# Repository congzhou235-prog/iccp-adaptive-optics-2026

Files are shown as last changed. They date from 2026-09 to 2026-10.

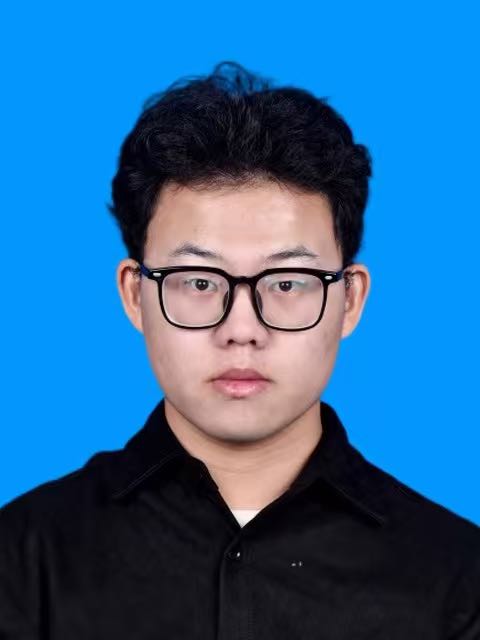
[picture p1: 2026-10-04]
lecturer&TAs pictures/jinxinliu.jpg

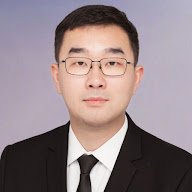
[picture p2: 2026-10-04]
lecturer&TAs pictures/shuqimu.jpg

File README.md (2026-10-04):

# ICCP Adaptive Optics Mini-Course 2026

Build a Shack-Hartmann sensor and learn to measure wavefront aberrations.

**[Open the course website](https://congzhou235-prog.github.io/iccp-adaptive-optics-2026/)**

## Course materials

- [Course notes](Hartmann%20Sensor%20Course%20Notes.pdf)
- [Lecture 1 introduction slides](Lecture1_introduction.pdf)
- [Hardware and parts list](hardware/README.md)
- [Assembly guide](Assembly%20Guide%20for%20the%20Hartmann%20Sensor.pdf)
- [Offline image analysis tutorial](sh_tutorial_prog/README.md)
- [Tutorial notebook](sh_tutorial_prog/main.ipynb)
- [Tutorial code and data on GitHub](https://github.com/congzhou235-prog/iccp-adaptive-optics-2026)

Lecturer: [He Sun](https://hesunpu.github.io/index.html) · Teaching assistant: [Shuqi Mu](https://scholar.google.com/citations?user=fEJv1TwAAAAJ&hl=en)

Visit the [PKU Computational Scientific Imaging Lab website](https://ai4scientificimaging.org/) to learn more about our group.

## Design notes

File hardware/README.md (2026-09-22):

# Shack-Hartmann sensor hardware

[Hardware section](../index.html#hardware) · [Parts list (CSV)](BOM.csv) · [Illustrated assembly guide](../Assembly%20Guide%20for%20the%20Hartmann%20Sensor.pdf)

The sensor uses a DAHENG VEN-161-61U3M bare-board camera, an LBTEK MLAS10-F15-P300-AB mounted microlens array, an SM1-12.5A lens tube, and a printed front and back housing.

## Supplier pages

- [Camera: VEN-161-61U3M](https://en.daheng-imaging.com/show-93-2117-1.html). Select the bare-board version without a lens mount for this housing.
- [Microlens array: MLAS10-F15-P300-AB](https://en.lbtek.com/product/378). Pitch: 300 µm. Focal length: 14.6 mm. Mount diameter: 25.4 mm.
- [Lens tube: SM1-12.5A](https://en.lbtek.com/product/221). Includes one SM1R retaining ring. The assembly needs two rings in total, so add one extra.

- [Retaining ring: SM1R](https://en.lbtek.com/product/135#SM1R). SM1 external thread, 2.0 mm thickness, Ø23.0 mm clear aperture, for Ø25.4 mm optics. Black anodized 6061-T6 aluminum alloy. Two rings are needed in total, including the one supplied with the lens tube.

Quantities in the CSV are for one sensor. Also prepare clean gloves, a computer with the camera driver and Galaxy Viewer, and a collimated beam for adjustment.

## Printed parts

The front housing holds the camera board and has an SM1 opening. The back housing secures the board and leaves the camera connector accessible. Four M2 screws and four M2×2 brass insert nuts join the two parts.

[Download both STEP models (ZIP)](../downloads/camera-housing-step.zip). Extract the archive to get a `camera-housing` folder containing both files.

Individual files:

- [hartmann1.STEP](../hartmann1.STEP)
- [hartmann2 - 0923new.step](../hartmann2%20-%200923new.step)

Dimensions for M2×2 from the supplier’s table (all in mm):

| Model | Length | Pilot hole diameter | Workpiece outer diameter |
| --- | --- | --- | --- |
| M2×2 | 3.5 | 3.2 | 6.2 |

The 6.2 mm value describes the workpiece outer diameter, not the nut outer diameter.

During printing, pause when the housing’s recessed holes are accessible. Use M2×2 brass insert nuts to fit the reserved holes. Press the four nuts into the recesses, then resume printing. Use the embedded nuts to secure the housing with the M2 screws.

Choose a strong printing material with good heat resistance. The specific material, print settings, and STL files are still to be added.

## Assembly

Follow the PDF for the illustrated steps: install the camera and housings, mount the array between two rings, attach the tube, connect the camera, and adjust focus and alignment. Tighten the housing screws and retaining rings gently.

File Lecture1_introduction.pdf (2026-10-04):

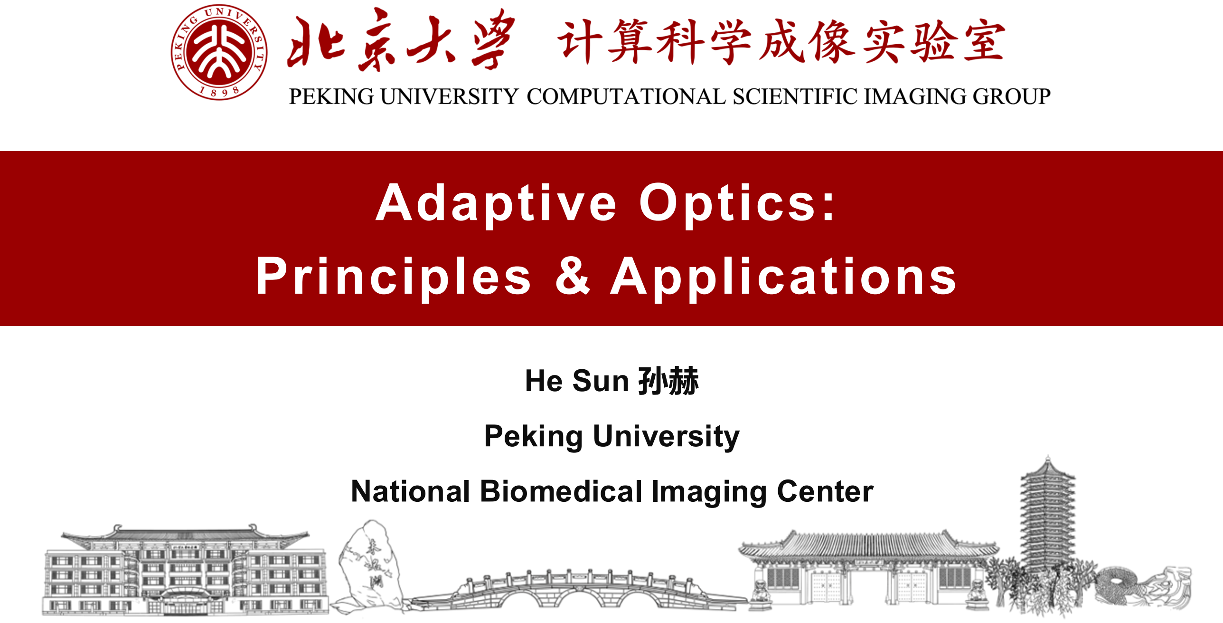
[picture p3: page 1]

## He Sun 孙赫

## Peking University

## National Biomedical Imaging Center

# Adaptive Optics: Principles & Applications

## What is Adaptive Optics?

## Adaptive optics (AO) is an ensemble of electro-optical and computational

methods that aim to recover the optimal performance of an optical system.

It is by nature interdisciplinary, related to optics, signal processing, control, etc.

## Science & Art of manipulating light physically & algorithmically

## — Nature Reviews Methods Primers 2021

## Adaptive Optics v.s. Computational Imaging

## Computational AO was proposed more than 20 years ago for correcting aberrations by … correcting the effects of the aberrations using deconvolution…

## Physical correction is preferred over deconvolution because the additional measurement of the corrected image yields additional photons, substantially increasing the signal to noise ratio …

This fact applies to AO in general and should not be understated.

## — Nature Reviews Methods Primers 2021

## History of Adaptive Optics – Newton’s Concern

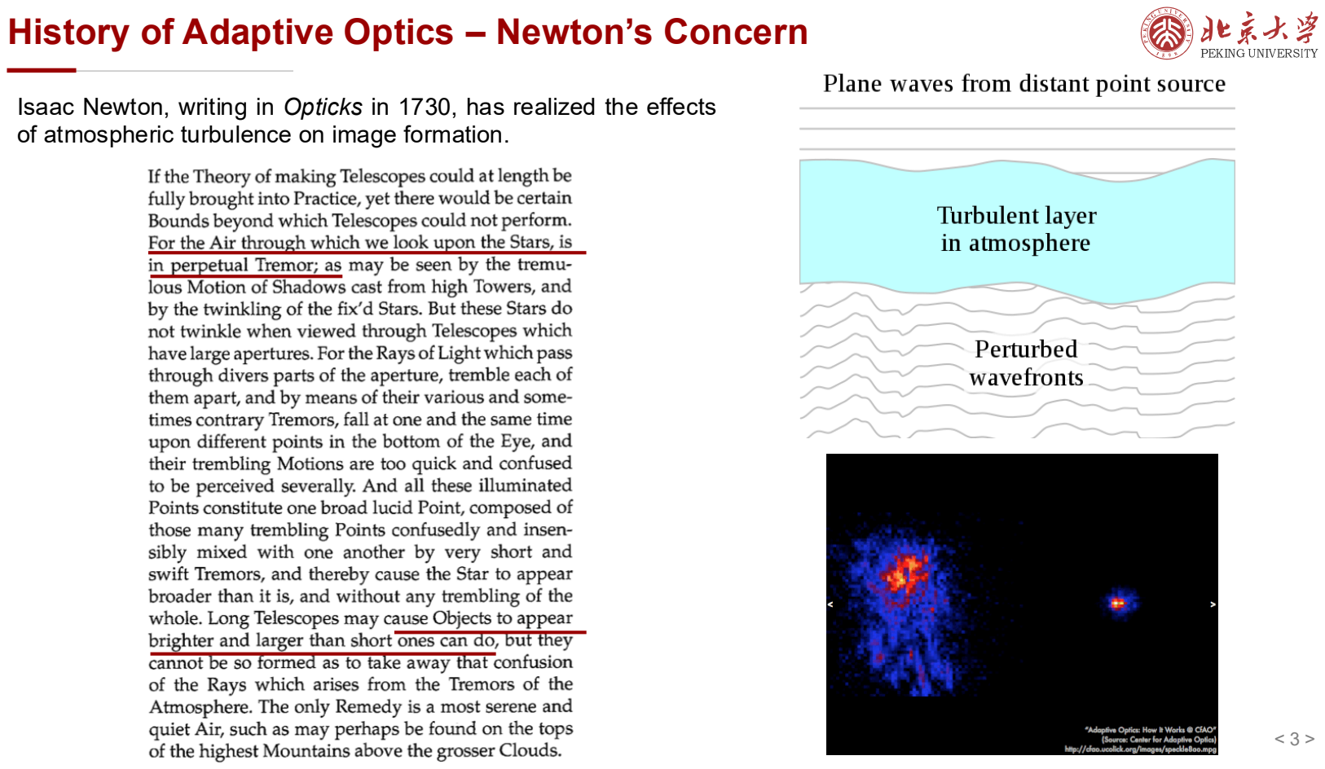
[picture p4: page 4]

Isaac Newton, writing in Opticks in 1730, has realized the effects of atmospheric turbulence on image formation.

## Wavefront Aberrations

Wavefront is defined by the spatial locations that share the same phase.

Optical aberrations can be understood as deformations of the light’s wavefront from its perfect form -planar for a collimated beam or spherical for a focusing beam - that produces the sharpest image

## Astronomical Seeing & Diffraction Limit

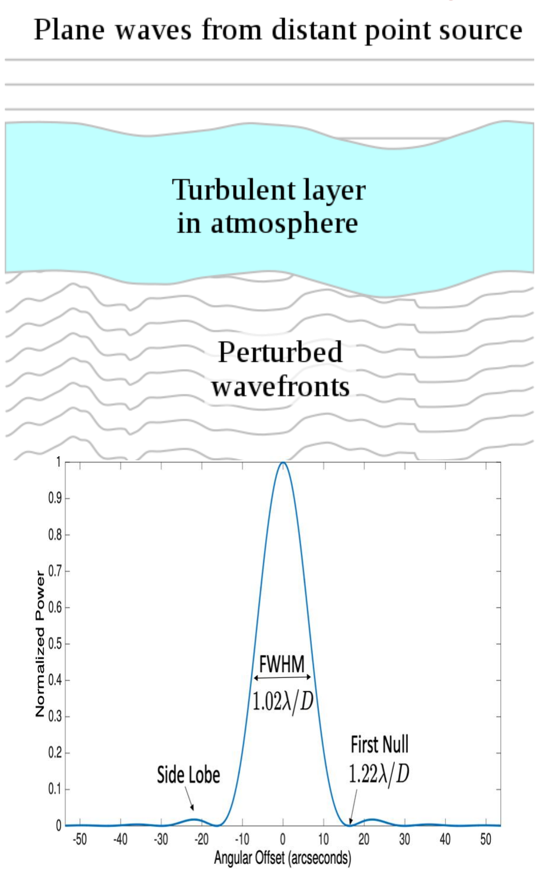
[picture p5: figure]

Seeing is the degradation of the image of an astronomical object due to turbulence in the atmosphere of Earth that may become visible as blurring, twinkling or
variable distortion.

Diffraction-limited image (Airy-pattern image)
R = 1.22 f λ/D

The model assumes that the wavefront perturbations are brought about by variations in the refractive index of the atmosphere.

Seeing is a major limitation to the angular resolution in astronomical observations with telescopes that would otherwise be limited through diffraction by the size of the telescope aperture.

## Statistical measure of atmospheric turbulence – r0 & t0

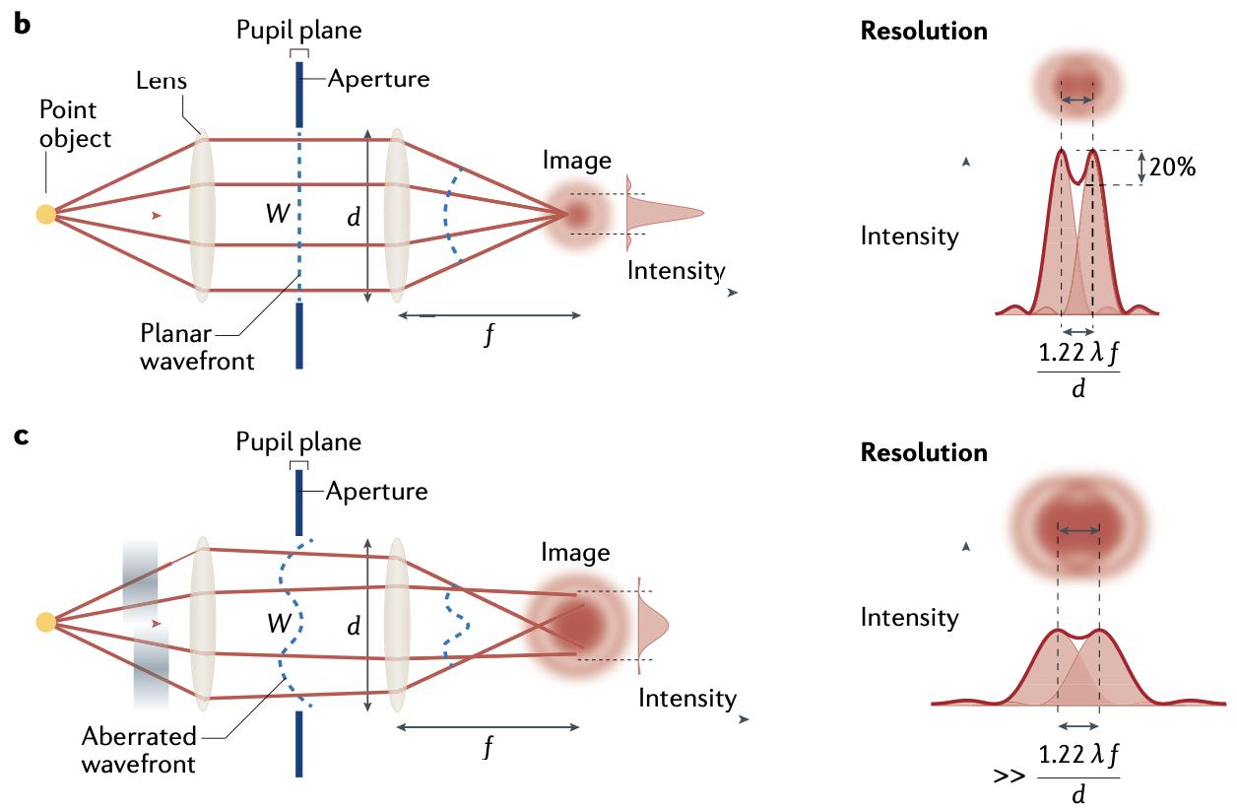
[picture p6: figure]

Coherent length or Fried parameter (r0

)
→ a statistical measure of the turbulence’s spatial frequency
→ around 10cm at visible wavelength at good site
→ telescope diameter < r0
, diffraction limit
defined by the telescope size; → telescope diameter > r0
, diffraction limit
defined by r0

Coherent time (t0

)
→ a statistical measure of the turbulence’s jiggling rate
→ on the order of 1ms

## Newton’s Proposal

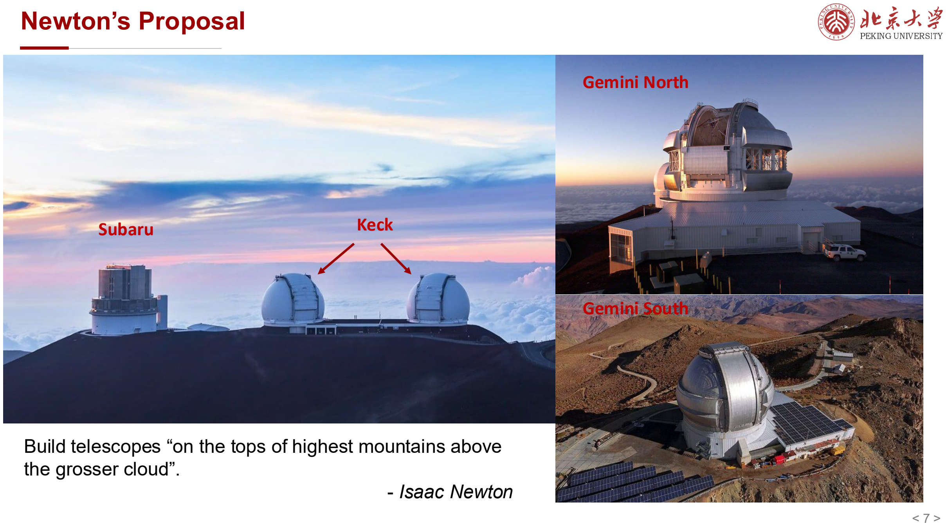
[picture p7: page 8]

Build telescopes “on the tops of highest mountains above the grosser cloud”.
- Isaac Newton
Subaru | Keck

Gemini North

Gemini South

## Newton’s Proposal

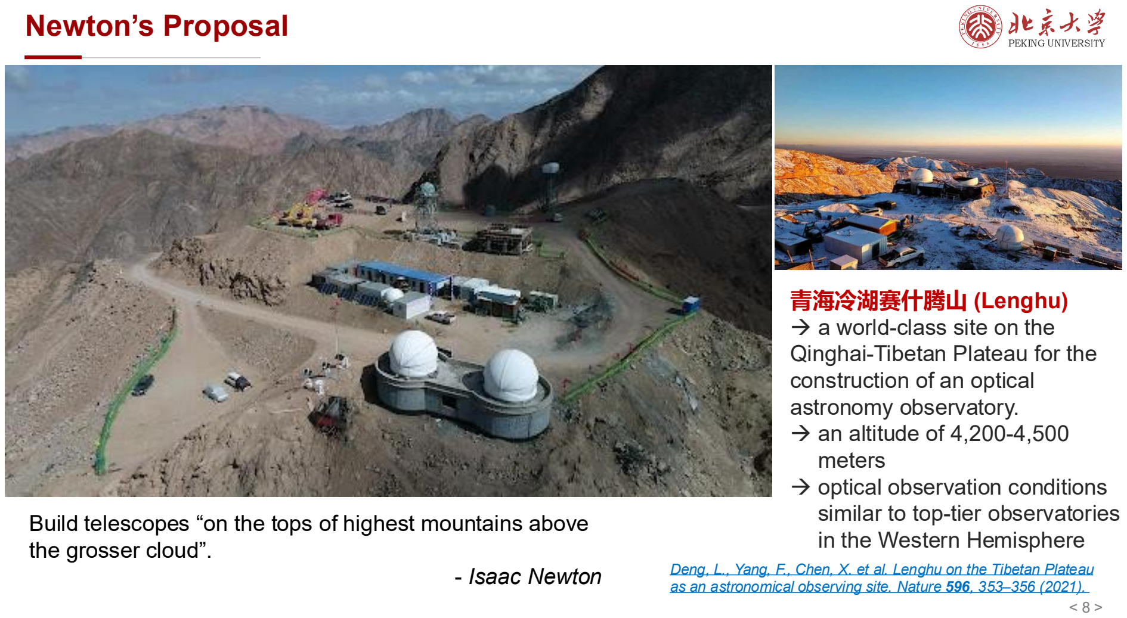
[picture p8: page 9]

Build telescopes “on the tops of highest mountains above the grosser cloud”.
- Isaac Newton

青海冷湖赛什腾山 (Lenghu)
→ a world-class site on the Qinghai-Tibetan Plateau for the construction of an optical astronomy observatory.
→ an altitude of 4,200-4,500 meters
→ optical observation conditions similar to top-tier observatories in the Western Hemisphere

Deng, L., Yang, F., Chen, X. et al. Lenghu on the Tibetan Plateau as an astronomical observing site. Nature 596, 353–356 (2021).

## 1950s - Babcock’s & Linnik’s Proposal

- 1953 AO seminal paper: "The Possibility of Compensating Astronomical Seeing”, PASP
- All basic building component is here
- Beam Splitter
- Wavefront Sensor & Corrector
- Close-loop Arrangement

Horace Babcock (U.S.A.)

V. P. Linnik (U.S.S.R) | Babcock’s Design
- 1957 Independent proposal for adaptive optics systems and their limitations, Opt. Spectrosc.
- First describe the artificial guide star

## 1960s – 1980s - AO Development During Cold War Years

- 1970s: DARPA (Defense Advanced Research Projects Agency) looks for a mean of identifying/imaging USSR low earth orbit satellites.
- Imaging fast moving target (>10kHz) in any seeing conditions, visible wavelength.
- Many technologies to develop:
- fast wave-front sensing (shearing interferometer)
- Reconstructor (analog, array of resistor; local)
- DM: Feinlieb et al ➜ MPM* 21 actuators
- More AO theory: WFSs for white light, extended sources.
- 1973-1974: the Real-Time Atmospheric Compensator (RTAC).
- 1973: First close loop lab test ever. Very successful.
- 1974: First RTAC field tests. Successful.
- 1980s: Strategic Defense Initiative (SDI) – Star War Program
- Ballistic Missile Defense
- Anti-Satellite
- 1990s: Many technologies declassified due to the end of cold war

AO off

AO on

AO on +
post-processing

1990s

## - Astronomical AO

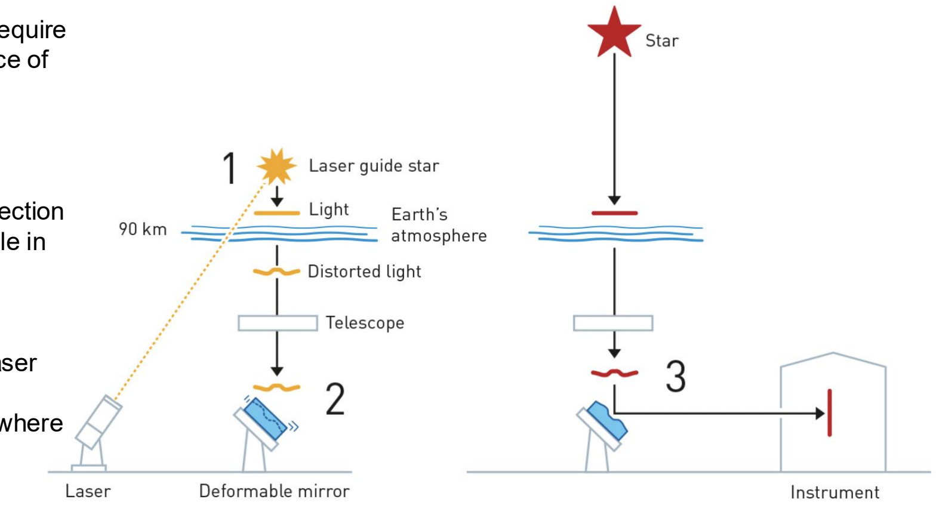
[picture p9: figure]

< 11

>

- Astronomical AO systems require a wavefront reference source of light called a guide star. • Natural guide star (NGS) • Ideal point source for

wavefront sensing/correction
- Bright stars not available in all parts of sky
- Laser guide star (LGS) • Created by shining a laser

into atmosphere
•

Can be positioned anywhere in the sky

## Laser Guide Star：Rayleigh Beacon v.s. Sodium Beacon

Rayleigh beacons
→ rely on the scattering of light by the molecules in the lower atmosphere around 20km altitude.
→ simple and inexpensive
→ cone effect: only measures the portion of atmosphere below the guide star

Sodium beacons
→ created by using a laser tuned to 589.2 nanometers to energize atoms in the sodium layer of the mesosphere at around 90 km altitude. The sodium atoms then re-emit the laser light, producing a glowing artificial star.

## Keck Telescope AO

- 1999: First light for AO on the Keck II telescope.
- First AO system for a new generation of 8–10 m telescopes,
- natural guide star system
- consisted of a separate tip–tilt corrector, a 349 actuator deformable mirror and a SH wavefront sensor
- Strehl ratios of up to 0.37 in H band (1.6 μm)
- dramatic improvements in image quality afforded by AO on large ground-based telescopes. The original Keck AO systems
- 2001: sodium LGS installed
- significantly improved sky coverage
- 2008: wavefront sensor and control upgraded
- Improved the sampling, frame rate and lantency
- Improved Strehl ratio and faint star limits for natural guide star and LGS modes86

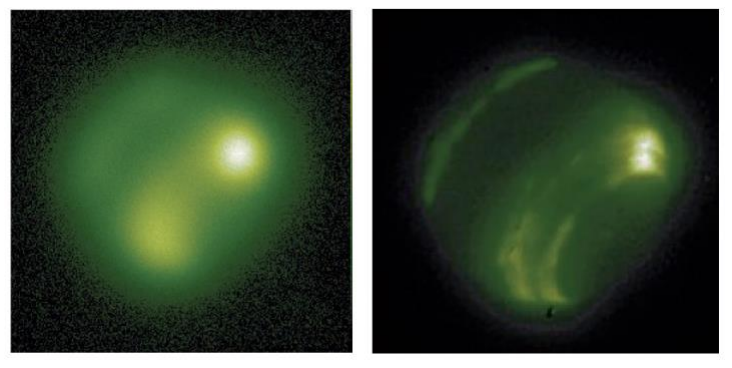
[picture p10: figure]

Neptune before and after AO correction

W. M. Keck Observatories

## AO for Black Hole Discovery

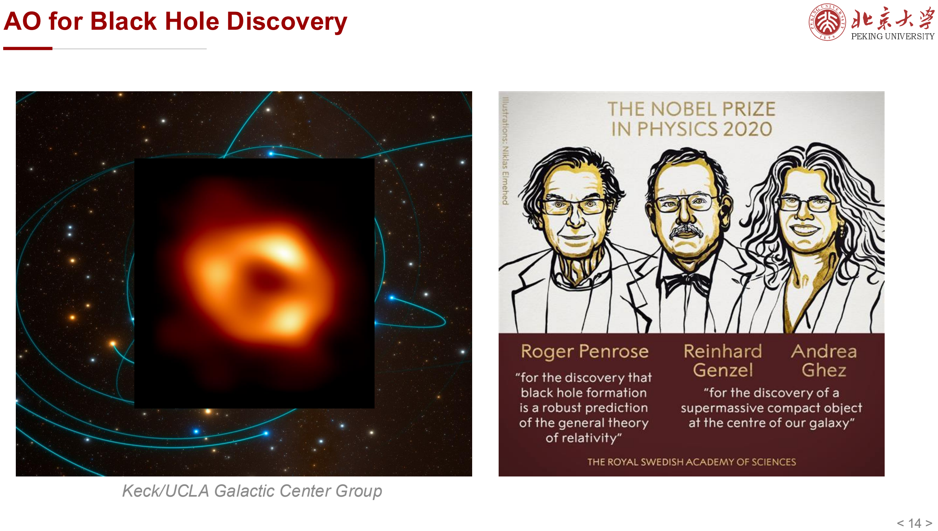
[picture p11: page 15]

Keck/UCLA Galactic Center Group

## Extreme AO – High Contrast Imaging of Exoplanets

The science target acts as the NGS.

HR8799 bcde

## AO cannot replace space facilities

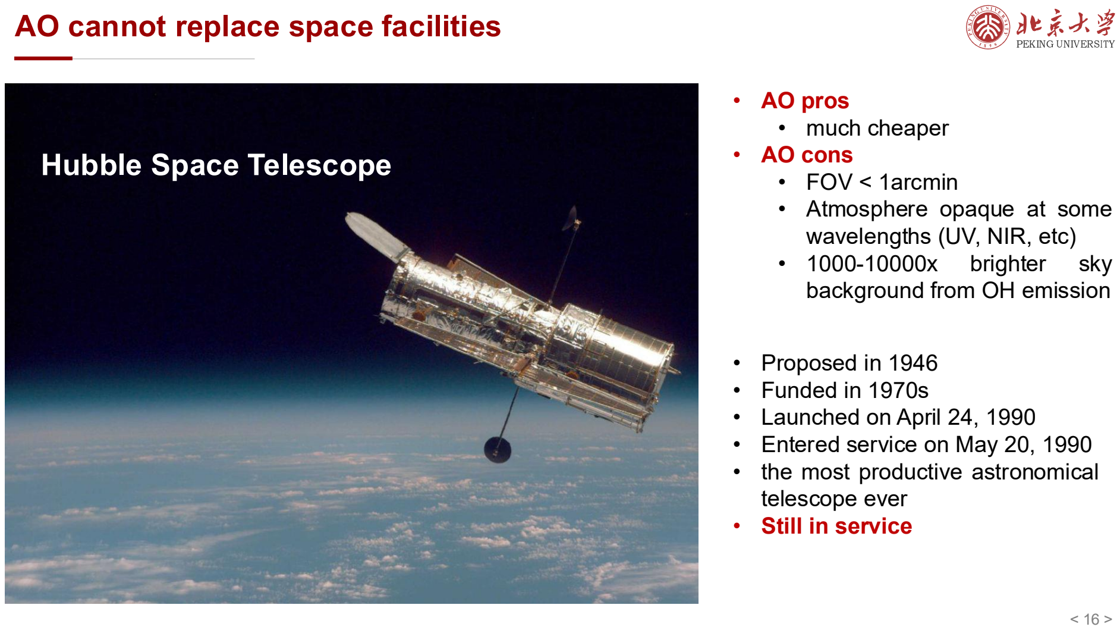
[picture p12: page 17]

- Proposed in 1946
- Funded in 1970s
- Launched on April 24, 1990
- Entered service on May 20, 1990
- the most productive astronomical telescope ever
- Still in service

## Hubble Space Telescope

- AO pros
- much cheaper
- AO cons
- FOV < 1arcmin
- Atmosphere opaque at some wavelengths (UV, NIR, etc)
- 1000-10000x | brighter | sky
background from OH emission

## Success of Hubble Space Telescope (HST)

Star birth in Eagle Nebula (Nov 2, 1995)

Hubble deep field image
(Jan 15, 1996)

## Back to 1990s: HST’s Flawed Mirror

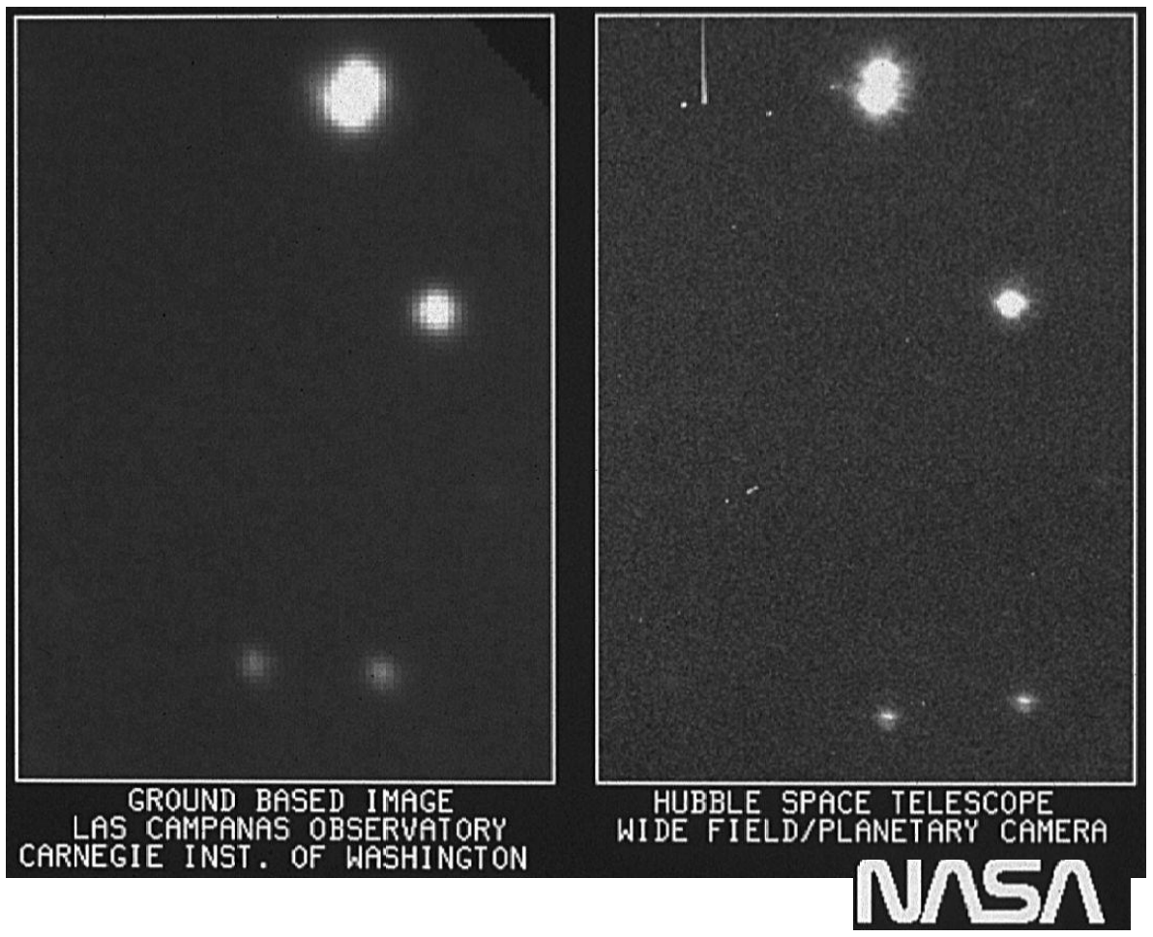
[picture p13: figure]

## Back to 1990s: HST’s Flawed Mirror

## Rescuing Hubble Space Telescope (HST)

Collect aberrated
images from HST

Characterizing
mirror flaws by
phase retrieval | Deploy corrective
| optics instrument

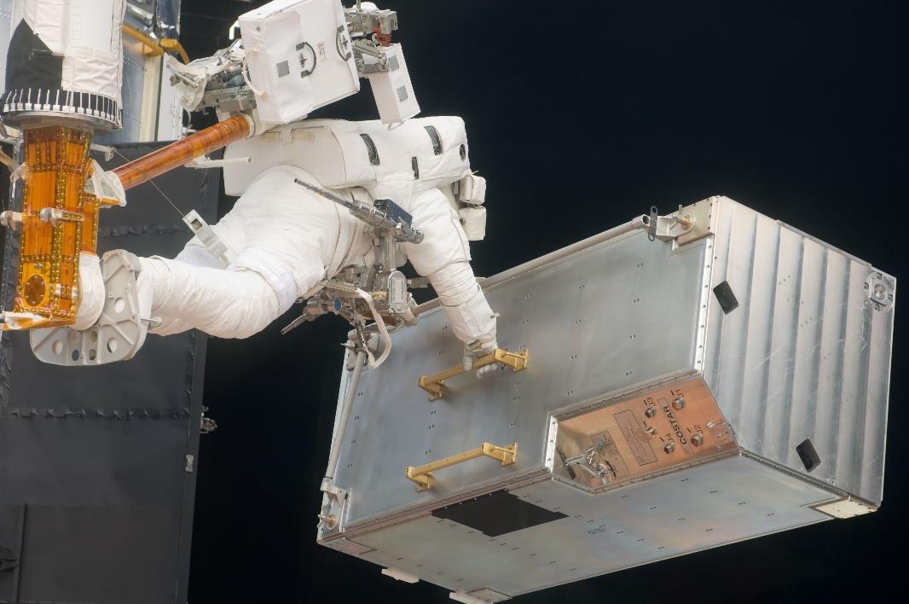
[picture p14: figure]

1993
HST Servicing
mission

Image processing
via deconvolution

## Rescuing Hubble Space Telescope (HST)

22

## Late 1990s - Vision AO

Aberrations in vision AO
- Eye’s imperfect optics
- Diffraction caused by the finite size of the eye’s pupil (1–8 mm diameter)
- Diffraction can be minimized by dilating the pupil with mydriatic drops. However, this benefit comes at the cost of additional aberrations exposed by dilation
- AO increases lateral resolution by a factor of up to five
- AO increases sensitivity as it allows a larger pupil to be used and more reflected light to be captured by the ophthalmoscope.

AO-OCT reveals thousands of individual cone photoreceptor cells spaced 4.5 μm apart that would otherwise not be seen

AO-OCT

## Early 2000s - Microscopic AO

2002 AO was first extended to the field of microscopy.

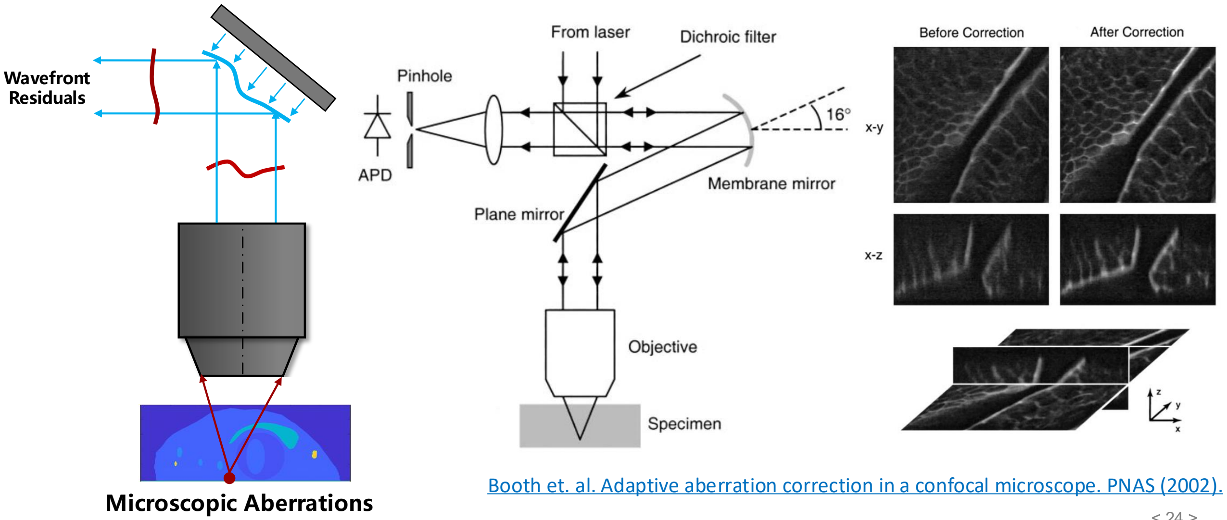
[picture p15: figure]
Wavefront Residuals; Microscopic Aberrations

Booth et. al. Adaptive aberration correction in a confocal microscope. PNAS (2002).

## Microscopic AO corrects illumination & emission light

Wide-Field (Emission) | Point Scanning (Excitation) | Light-Sheet (Emission & Excitation)

## Recent Progress: Multi-photon & Super-resolution

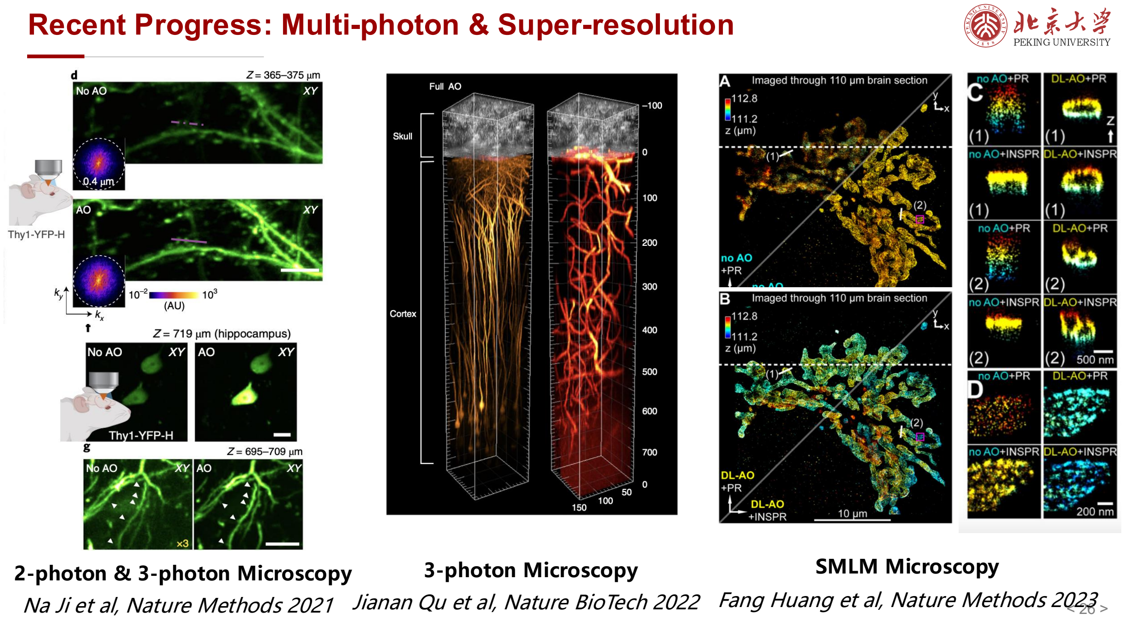
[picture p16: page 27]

2-photon & 3-photon Microscopy Na Ji et al, Nature Methods 2021

SMLM Microscopy
Fang Huang et al, Nature Methods 2023

3-photon Microscopy
Jianan Qu et al, Nature BioTech 2022

## A Representative AO System

Three main components of AO:
- a sensor to measure the aberrations
- a corrector to compensate the aberrations
- a controller that calculates the required signals sent to the corrector based on the sensor measurements.

The corrector and sensor are typically conjugate to the pupil plane of the imaging system, which means that the pupil is imaged on to the corrector and sensor.

## Representing the Wavefront - RMS errors & Zernike Polynomials

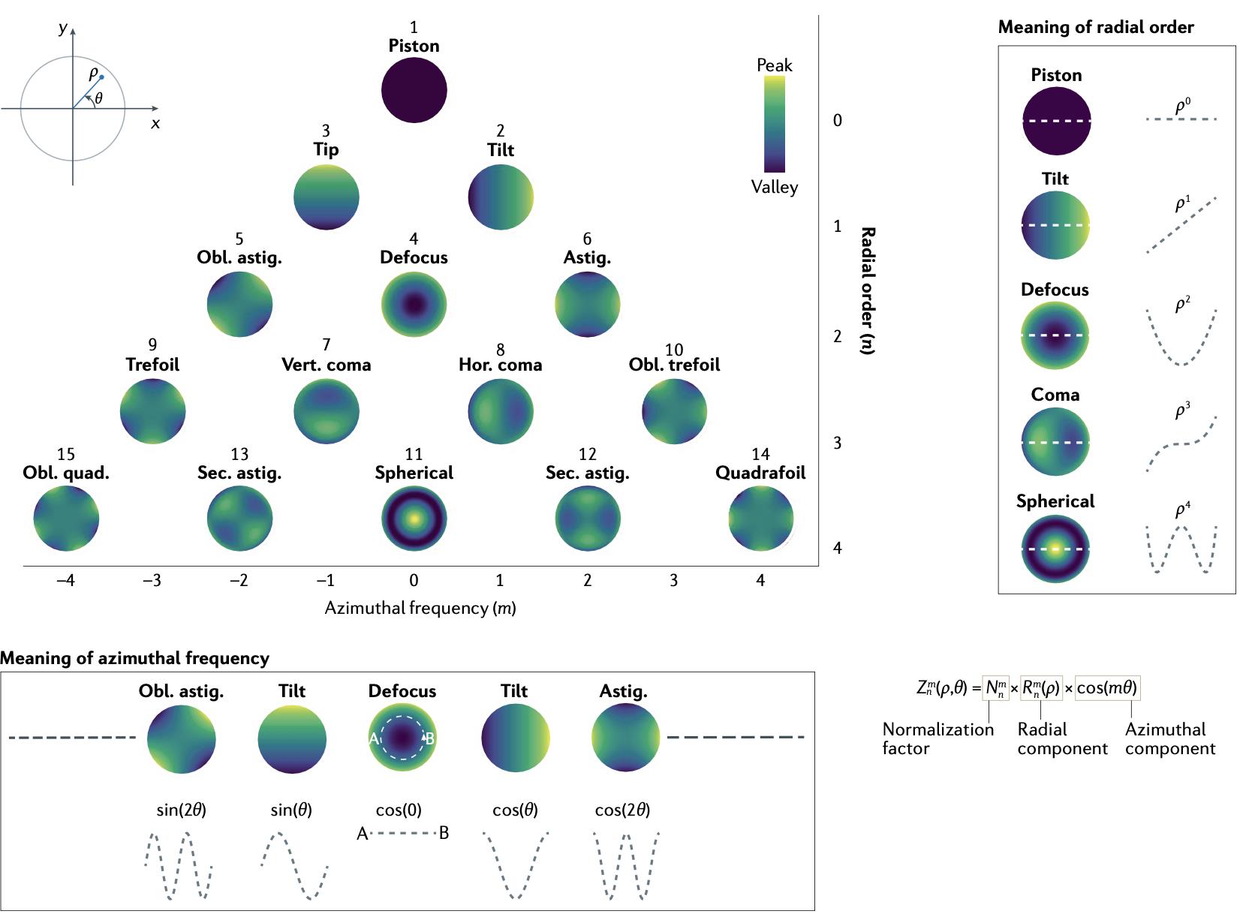
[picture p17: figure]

- Aberration modes are often broadly categorized as being of lower order or higher order.
- The definition of lower order and higher order varies
between fields.
- Higher order is typically defined as modes with a radial order above three for astronomy, above two for vision science and above four for microscopy.

## Wavefront Sensing – Direct Sensing

## Wavefront Sensing – Indirect Sensing

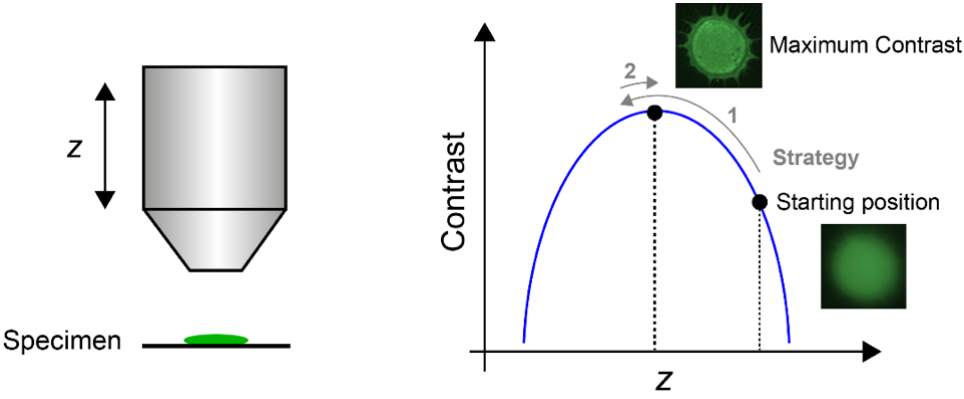
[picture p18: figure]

## Wavefront Sensing – Indirect Sensing

## Wavefront Control – Phase Conjugation

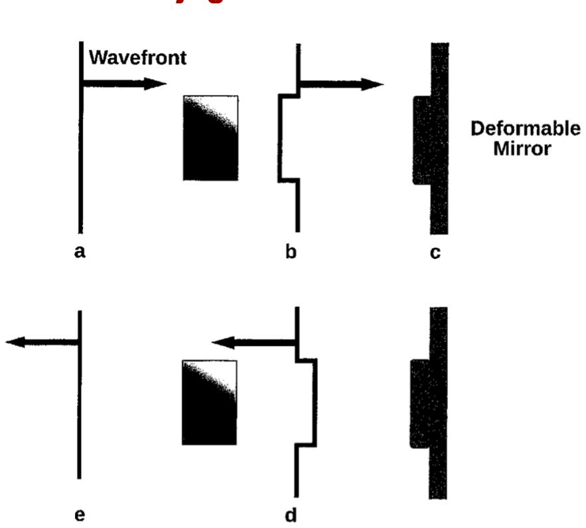
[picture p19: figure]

Apply an opposite shape of wavefront error on the corrector

## Wavefront Control - Correctors

a. Deformable mirrors (DMs) consist of a reflective surface that may be continuous or segmented.
b. Liquid crystal spatial light modulators (LCSLMs) consist of pixels that are able to change their refractive index, n.
c. Deformable phase plates are fluidic devices that are able to change their shape.

## Wavefront Control - Correctors

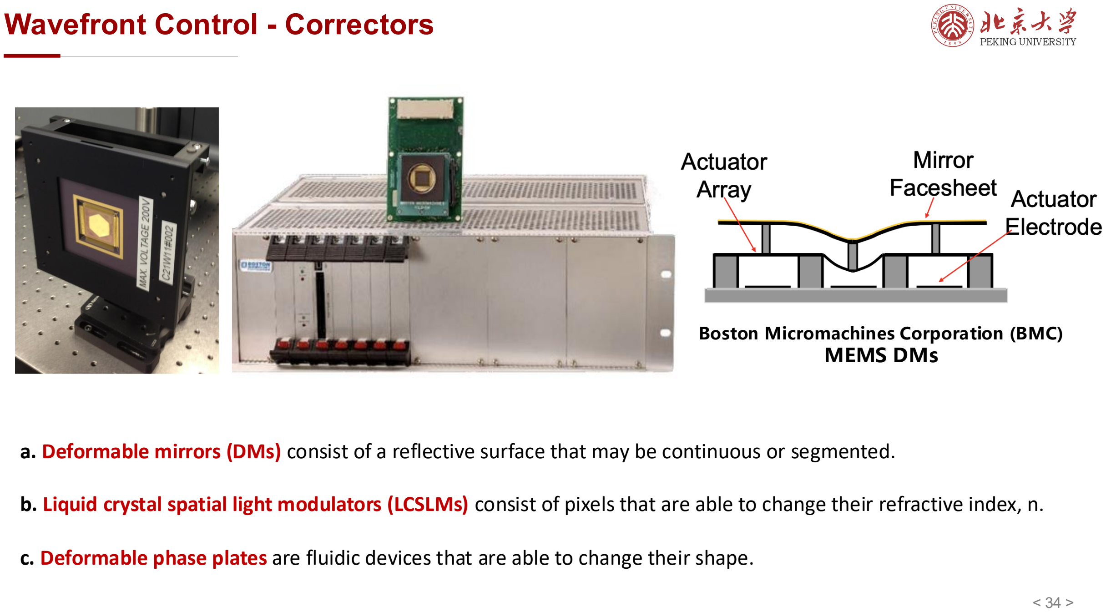
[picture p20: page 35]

a. Deformable mirrors (DMs) consist of a reflective surface that may be continuous or segmented.
b. Liquid crystal spatial light modulators (LCSLMs) consist of pixels that are able to change their refractive index, n.
c. Deformable phase plates are fluidic devices that are able to change their shape.

Boston Micromachines Corporation (BMC) MEMS DMs

## Basic Concept – Strehl Ratio

Strehl Ratio: The ratio of the intensity of the peak of the aberrated point spread function (PSF) to that of the diffraction-limited PSF.

To achieve diffraction-limited resolution, which is equivalent to a Strehl ratio of 0.8 or above, AO must reduce this distortion to less than λ/14.

## Basic Concept – RMS Error

RMS wavefront error is a useful descriptor to capture the severity of the aberrations in a system.
RMS = E | W − E | W | 2

1/2

The Maréchal Approximation： Strehl Ratio ~ exp −σ

2 = exp −(2π RMS/λ)

2
Another empirical rule： phase variance = σ

2 = 1.03 D/r0

5/3

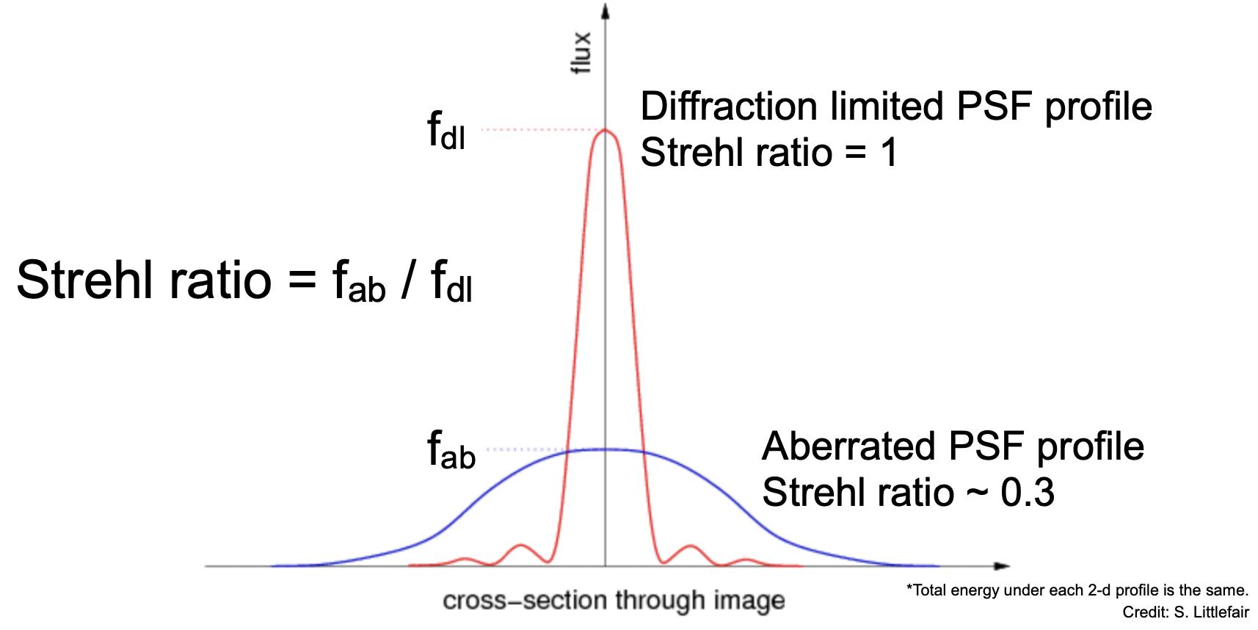
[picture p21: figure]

## Basic Concept – Isoplanatic Patch

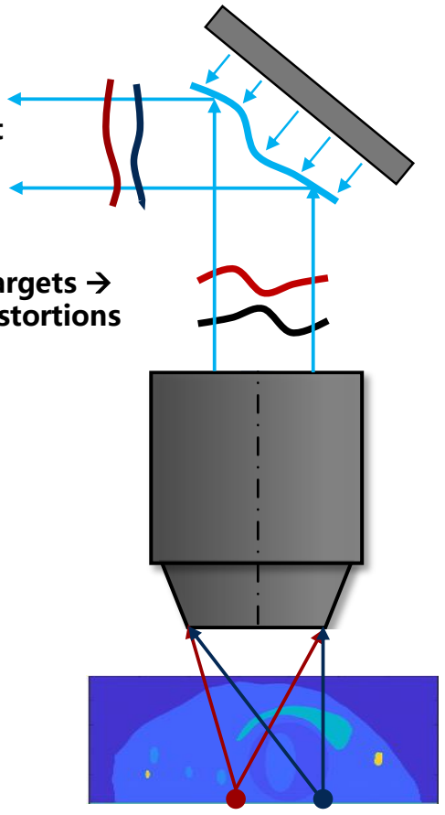
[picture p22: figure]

Isoplanatic patch: The area over which the aberrations can be considered invariant.

- astronomy: 1.5 to 2 arcsec at 0.5μm Isoplanatic path ∝ 1.03 D/r0

6/5

- vision science: 1°, or 300 μm at the retina
- microscopy: hundreds of microns, in mouse brain for example, to a few microns, such as inside tissue with high curvature or complexity, for example, zebrafish larvae or Caenorhabditis elegans.

### Classification of AO systems: Single-Conjugate v.s. Multi-Conjugate

Single Conjugate AO (SCAO), i.e. classical AO, → a single DM conjugated to turbulence in a single atmospheric layer.
→ a moderate FOV at a moderate Strehl ratio.

Ground Layer AO (GLAO)
→ a single DM conjugated to ground level.
→ Large FOV at low Strehl ratio

Multi-conjugate AO (MCAO)
→ multiple WFSs and DMs conjugated to multiple atmospheric layers and requires multiple guide stars. → Large FOV at moderate Strehl ratio

MCAO

Classicial AO

Francois Rigaut et al, MNRAS 2014

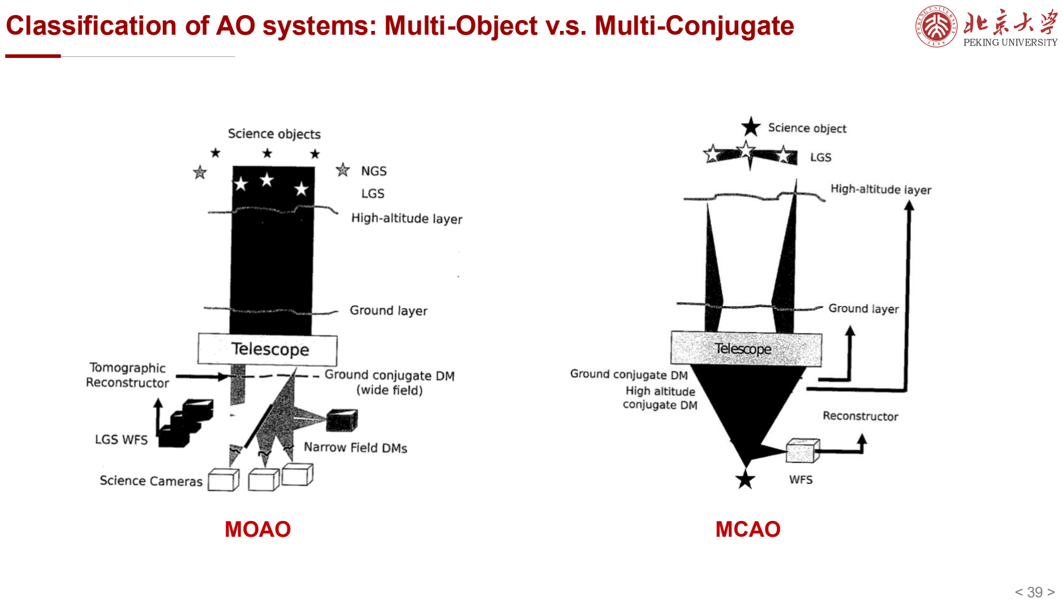
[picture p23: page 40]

### Classification of AO systems: Multi-Object v.s. Multi-Conjugate

MOAO | MCAO

## Classification of AO systems: Sensorless or Sensor-based

Pros of sensorless AO:
- It requires no extra hardware → low cost
- There are no non-common path errors,
- All light is used for imaging → good for low light case
- It can be used in situations where sensing may not be possible owing to the nature of the light returning from the sample → deep tissue imaging

Cons of sensorless AO:
- Speed → photobleaching, live specimen motion, mechanical drift https://aomicroscopy.org/sensorless-ao

Sensor-based AO consisted of a wavefront sensor for aberration measurement.

Sensorless AO requires no sensor, but infers the wavefront aberrations from a sequence of images.

## Classification of AO systems: Point v.s. Extended Source

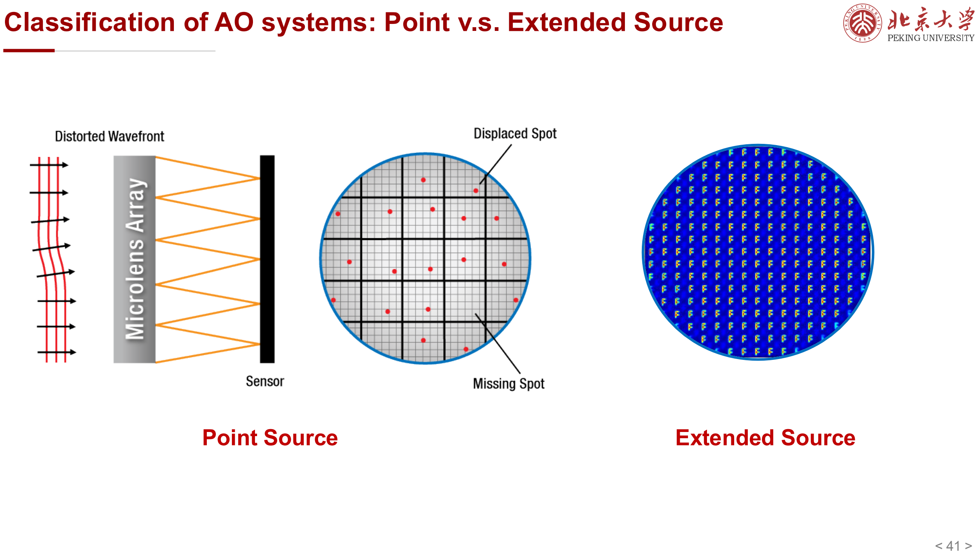
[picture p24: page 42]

Point Source | Extended Source

## Classification of AO systems: Zonal v.s. Model Correction

The wavefront errors can be corrected either zonally or modally.

In the zonal case, the pupil is considered to consist of segments that are individually controlled. Zonal techniques are typically carried out using phase-only liquid crystal spatial light modulators (LC-SLMs) or segmented deformable mirrors. Piston-only or piston, tip and tilt are modulated, depending on the corrector.

In the modal case, the wavefront shape across the entire pupil is changed sequentially. Consequently, this method is more suitable for continuous surface correctors such as continuous surface deformable mirrors. Each mode could be a Zernike polynomial, for example.

## Classification of AO systems: AO v.s. Wavefront Shaping

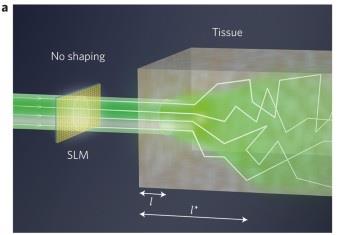
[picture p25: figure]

AO and wavefront shaping are identical, except for the controller’s degrees of freedom.

AO is mainly correct for smooth aberrations.

## Wavefront shaping compensate both scattering and aberrations (mainly scattering) and have guaranteed convergence even for

finding high-dimensional corrections.

## Astronomical AO v.s. Vision AO v.s. Microscopy AO

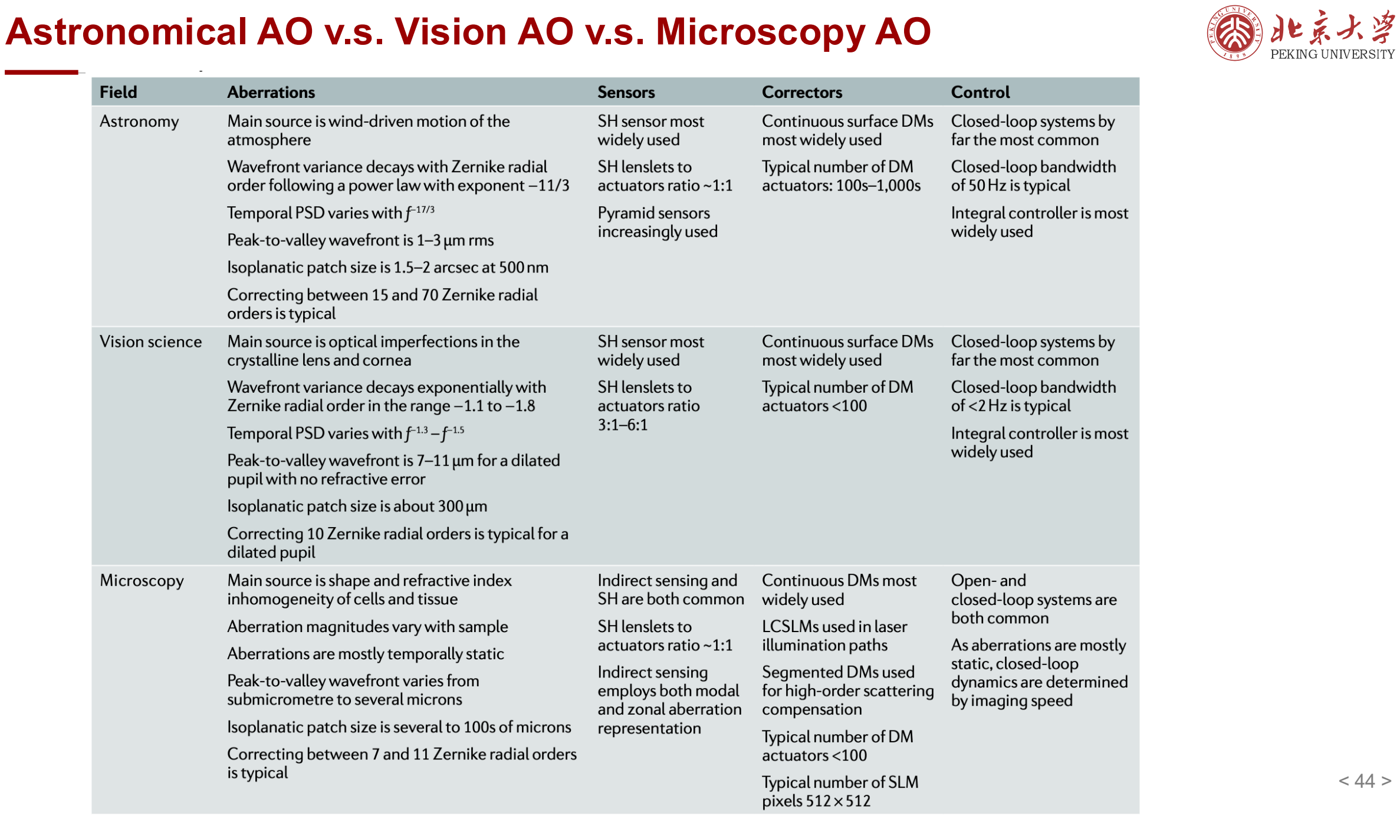
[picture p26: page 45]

## Analysis of AO System

< 45

>

Problem:
Science Target:
Wavelength Range:
Statistics of Aberrations: ⋯

Hardware&Software

:
Sensor:
Corrector:
Algorithm:

Result:
FOV:
Speed:
Resolution:
Contrast:

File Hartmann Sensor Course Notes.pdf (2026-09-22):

## Hartmann Sensor Course Notes

## 1 Light and Wavefronts

Before we build a Hartmann sensor, we need to understand one important idea:

Light is not only a ray. Light is also a wave.

A simple way to imagine a wave is to think about water ripples. If we drop a small stone into water, circular ripples spread outward. Light also has a similar wave-like behavior, although we usually cannot see the wave directly.

### 1.1 What is a wavefront?

A wavefront is a surface connecting points of a light wave that are at the same stage of vibration. In simple words:

Key Idea

A wavefront shows the shape of light as it travels.

The direction of light propagation is usually perpendicular to the wavefront. So if we know the shape of the wavefront, we can understand how the light is moving.


Figure 1: Three examples of wavefronts: planar wavefront, spherical diverging wavefront, and distorted wavefront. The black arrows show the direction of light propagation. The purple curves show the wavefronts.

In a perfect world, light would travel smoothly. But in real optical systems, many things can disturb the wavefront:

- imperfect lenses,
- turbulent air,
- biological tissue,
- misaligned optical components.

After passing through these disturbances, the wavefront is no longer flat or spherical. It becomes a distorted wavefront.

### 1.2 Why do we care about wavefronts?

In imaging systems, the quality of the image is strongly related to the quality of the wavefront. If the wavefront is flat and smooth, the image can be sharp. If the wavefront is distorted, the image may become blurry.
So our goal is:

Measure the wavefront, understand the distortion, and correct it.

This is the basic idea behind adaptive optics.


Figure 2: Ideal and irregular wavefronts in an imaging system. In the ideal case, light rays focus well and form a sharp point. In the irregular case, the distorted wavefront prevents the rays from meeting at one perfect focus, so the image becomes blurred.

This is similar to how the human eye forms an image. In a healthy eye, the wavefront is smooth, so light can focus well on the retina and we see a clear image. But if the cornea or lens is not perfect, the wavefront becomes distorted. Then the light cannot focus into a sharp point, and the image becomes blurry.

### 1.3 A Simple Language for Wavefronts: Zernike Modes

A distorted wavefront can have many different shapes. Some distortions are simple, while others are more complicated.
To describe these shapes, optical scientists often use Zernike modes.
A simple way to understand Zernike modes is:

Zernike modes are basic building blocks of wavefront distortion.

Each Zernike mode represents one simple type of wavefront shape. For example:

- Tilt: the wavefront is slanted.
- Defocus: the focus moves forward or backward.
- Astigmatism: the wavefront focuses differently in different directions.
- Coma: the wavefront becomes asymmetric, like a comet tail.
- Spherical aberration: the center and edge of the wavefront focus differently.


Figure 3: Examples of Zernike modes. Each circular pattern represents one basic type of wavefront shape. By combining many Zernike modes, we can describe a more complicated distorted wavefront.

Mathematically, a wavefront can be written as a sum of Zernike modes:

W(ρ, θ) = X

i

aiZi(ρ, θ)

Here:

- W(ρ, θ) is the wavefront shape.
- Zi(ρ, θ) is one Zernike mode.
- ai
is the coefficient of that mode.

The coefficient ai tells us how much of that Zernike mode is present in the wavefront.

Key Idea

Zernike coefficients tell us what kind of distortion exists in the wavefront, and how strong each distortion is.

### 1.4 From Wavefront to Hartmann Sensor

Now we know that the shape of a wavefront is very important. A smooth wavefront usually gives a sharp image, while a distorted wavefront can make the image blurry.
But there is one problem:

We cannot see the wavefront directly.

So we need a tool to measure it.
The Hartmann sensor is a useful tool for this purpose. It helps us detect whether the incoming wavefront is flat, tilted, or distorted.
In this course, we will learn how to build a simple Hartmann sensor and use it to study wavefront distortion.

Main Message

A Hartmann sensor is a tool for measuring wavefront distortion.

## 2 How Does a Hartmann Sensor Work?

In the previous section, we learned that a distorted wavefront can make an image blurry. Now we need a tool to measure the wavefront.
A Hartmann sensor is a simple and powerful tool for this job. It does not measure the whole wavefront directly. Instead, it measures the local direction of light at many small positions.

### 2.1 The Key Part: A Microlens Array

The most important part of a Hartmann sensor is the microlens array. It is a plate with many tiny lenses arranged in a regular grid.
Each small lens is called a lenslet. Each lenslet focuses a small part of the incoming light onto a camera.


Figure 4: A microlens array. It contains many small lenses. Each small lens can focus one small part of the incoming wavefront.

A simple way to think about it is:

A microlens array cuts one big wavefront into many small pieces.

Each small piece of the wavefront creates one bright spot on the camera.

### 2.2 From Wavefront Direction to Spot Position

If the incoming wavefront is flat, the light reaches each lenslet straight. Then the spots appear at regular positions on the camera.

If the wavefront is tilted or distorted, the local light direction changes. Then the focused spot moves away from its normal position.


Figure 5: Basic principle of a Hartmann sensor. Each lenslet focuses light onto the sensor. If the local wavefront is tilted, the spot position shifts. The spot displacement tells us the local slope of the wavefront.

This is the central idea:

Key Idea

The movement of each spot tells us the local slope of the wavefront.

### 2.3 Reference Spots and Distorted Spots

In practice, we usually take two images:

- a reference image, measured with a flat or known wavefront;
- a distorted image, measured with the unknown wavefront.

For each lenslet, we compare the new spot position with the reference spot position.
If a spot moves to the right, it means the local wavefront is tilted in the x direction. If a spot moves upward or downward, it means the local wavefront is tilted in the y direction.

∆x = xdistorted − xreference

∆y = ydistorted − yreference

Here, ∆x and ∆y are the spot displacements.

### 2.4 Spot Displacement and Wavefront Slope

The spot displacement is related to the local wavefront slope.
If the focal length of each lenslet is f, then we can write approximately:

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
Here:

- W is the wavefront shape;
•
∂W
∂x and ∂W
∂y are the local slopes of the wavefront;
- ∆x and ∆y are the measured spot shifts;
- f is the focal length of the microlens.

Main Message

A Hartmann sensor changes an invisible wavefront problem into a visible spot movement problem.

### 2.5 From Spot Shifts to Wavefront Reconstruction

Now we know that each spot displacement gives us the local slope of the wavefront. For the k-th lenslet, we measure the spot position in two images:

- reference spot position: (x
0
k

, y⁰
k

)

- distorted spot position: (xk, yk)

The spot displacement is

∆xk = xk − x

0
k

∆yk = yk − y

0
k
If the focal length of the microlens is f, then the local wavefront slopes are approximately

sx,k =

∂W
∂x (xk, yk) ≈

∆xk
f

sy,k =

∂W
∂y (xk, yk) ≈

∆yk
f

Here, sx,k and sy,k are the measured local slopes of the wavefront.

Important Idea

The Hartmann sensor does not directly measure the wavefront height W. It measures the wavefront slope.

### 2.6 Using Zernike Modes to Describe the Wavefront

To reconstruct the full wavefront, we need a mathematical model.
A common choice is to describe the wavefront as a sum of Zernike modes:

W(x, y) = X

N

j=1

ajZj (x, y)

Here:

- W(x, y) is the unknown wavefront;
- Zj (x, y) is the j-th Zernike mode;It is a known function, like a predefined wavefront pattern;
- aj is the Zernike coefficient;
- N is the number of Zernike modes we use.

The goal of wavefront reconstruction is to find the unknown coefficients

a1, a2, · · · , aN

Once we know these coefficients, we know the wavefront shape.

### 2.7 Building the Linear Equations

Because the Hartmann sensor measures slopes, we take derivatives of the Zernike expansion:

∂W
∂x =

X

N

j=1

aj

∂Zj
∂x

∂W
∂y =

X

N

j=1

aj

∂Zj
∂y

For each lenslet position (xk, yk), we get two equations:

sx,k =

X

N

j=1

aj

∂Zj
∂x (xk, yk)

sy,k =

X

N

j=1

aj

∂Zj
∂y (xk, yk)

So one lenslet gives two pieces of information:

x-slope and y-slope

If we have many lenslets, we get many equations.

### 2.8 Matrix Form

All equations can be written in one matrix equation:

b = Aa

where

b =

sx,1

sy,1

sx,2

sy,2

sx,K

sy,K

is the measured slope vector,

a =

a1
a2
aN

is the unknown Zernike coefficient vector.
The matrix A contains the derivatives of the Zernike modes at each lenslet position:

A =

∂Z1
∂x (x1, y1)

∂Z2
∂x (x1, y1) · · ·

∂ZN
∂x (x1, y1)

∂Z1
∂y (x1, y1)

∂Z2
∂y (x1, y1) · · ·

∂ZN
∂y (x1, y1)

∂Z1
∂x (x2, y2)

∂Z2
∂x (x2, y2) · · ·

∂ZN
∂x (x2, y2)

∂Z1
∂y (x2, y2)

∂Z2
∂y (x2, y2) · · ·

∂ZN
∂y (x2, y2)

Here, K is the number of valid lenslets.

### 2.9 Solving the Equation

Usually, we have more equations than unknowns. So we solve the system using least squares:

aˆ =

AT A

−1 ATb

This gives the estimated Zernike coefficients. Then the reconstructed wavefront is

Wˆ (x, y) = X

N

j=1

aˆjZj (x, y)

Complete Measurement Mechanism

Spot image → spot centers → spot displacements → local slopes → Zernike coefficients → reconstructed wavefront.

### 2.10 A Small Note

The Hartmann sensor measures wavefront slopes, not absolute wavefront height. So the constant part of the wavefront, often called piston, cannot be measured from spot shifts.
In most imaging applications, this is not a serious problem, because piston does not change the image sharpness.

### 2.11 What Do We Finally Get?

After measuring many spot shifts, we know the local slope of the wavefront at many positions. Then we can reconstruct the full wavefront shape.
So the complete idea is:

Wavefront distortion → spot displacement → local slope → wavefront reconstruction

This is why a Hartmann sensor is very useful in adaptive optics. It tells us how the wavefront is distorted, so that we can later correct it.

## 3 Adaptive Optics Demo: Optical Path and Correction Idea

In this part, we introduce the optical path used in our adaptive optics demo.
The goal is simple:

Add a wavefront distortion, measure it, and then correct it.

In our setup, the SLM is used to control the wavefront. The Hartmann sensor is used to measure the wavefront. The camera is used to observe the imaging result.


Figure 6: Optical path of the adaptive optics demo. The 635 nm light source passes through the SLM, lenses, beam splitter, camera path, and Hartmann sensor path.

### 3.1 Main Components

The optical path contains several important parts:

- 635 nm light emitter: provides the input light.
- SLM: adds or corrects the wavefront phase.
- Convex lenses: help relay and focus the light.
- Beam splitter: divides the light into two paths. One path goes to the camera, and the other path goes to the Hartmann sensor.
- Camera: observes the imaging quality.
- Hartmann sensor: measures the wavefront distortion.

The most important idea is that the light is divided into two useful paths:

- one path goes to the camera, so we can see the image;
- one path goes to the Hartmann sensor, so we can measure the wavefront.

### 3.2 Using the SLM to Add a Wavefront

The SLM can change the phase of the light.
In our demo, we first use the SLM to intentionally add a known wavefront distortion. For example, we can add defocus, astigmatism, or coma.
We can write this artificial distortion as

Wadd(x, y)

This means that the SLM is now making the wavefront worse on purpose.

Why do we add distortion on purpose?

We add a known distortion because it gives us a clear test. If our system works, it should be able to measure this distortion and remove it.

### 3.3 Measuring the Added Wavefront

After the SLM adds the distortion, the distorted light reaches the Hartmann sensor.
The Hartmann sensor records the spot pattern. From the spot shifts, we reconstruct the measured wavefront:

Wmeas(x, y)

Ideally, the measured wavefront should be close to the wavefront added by the SLM:

Wmeas(x, y) ≈ Wadd(x, y)

This means the Hartmann sensor has successfully detected the distortion.

### 3.4 Correction: Adding the Opposite Wavefront

Now comes the core idea of adaptive optics.
If the SLM adds a distortion

Wadd(x, y)

then we can correct it by adding the opposite wavefront:

Wcorr(x, y) = −Wmeas(x, y)

If the measurement is accurate, then

Wcorr(x, y) ≈ −Wadd(x, y)

So the total wavefront becomes

Wtotal(x, y) = Wadd(x, y) + Wcorr(x, y)

Substituting the correction term gives

Wtotal(x, y) ≈ Wadd(x, y) − Wadd(x, y) = 0

This means the wavefront becomes nearly flat again.

Key Idea

The SLM first adds a bad wavefront. Then we calculate the opposite wavefront and send it back to the SLM. The bad wavefront and the opposite wavefront cancel each other.

### 3.5 Closed-Loop Correction

In a real experiment, one correction may not be perfect. So we can repeat the process several times. At each step, the Hartmann sensor measures the remaining wavefront error. Then the SLM applies a new correction.
A simple update rule is

W⁽n+1)

corr (x, y) = W⁽n) corr(x, y) − gW⁽n)
meas(x, y)

Here:
- W

(n)
corr is the correction wavefront at step n;
- W

(n)
meas is the wavefront measured by the Hartmann sensor;
- g is a small gain factor, usually between 0 and 1.

The gain g controls how strongly we correct the wavefront each time.
If g is too small, the correction is slow. If g is too large, the system may become unstable.

### 3.6 What Should We See?

Before correction, the wavefront is distorted. The camera image may look blurred or deformed. After correction, the wavefront becomes flatter. The camera image should become sharper. So the full adaptive optics loop is:

SLM adds distortion → Hartmann sensor measures it → computer calculates opposite wavefront → SLM applies correction → image becomes better

Main Message

Adaptive optics is a feedback system. It measures the wavefront error and applies the opposite wavefront to reduce that error.

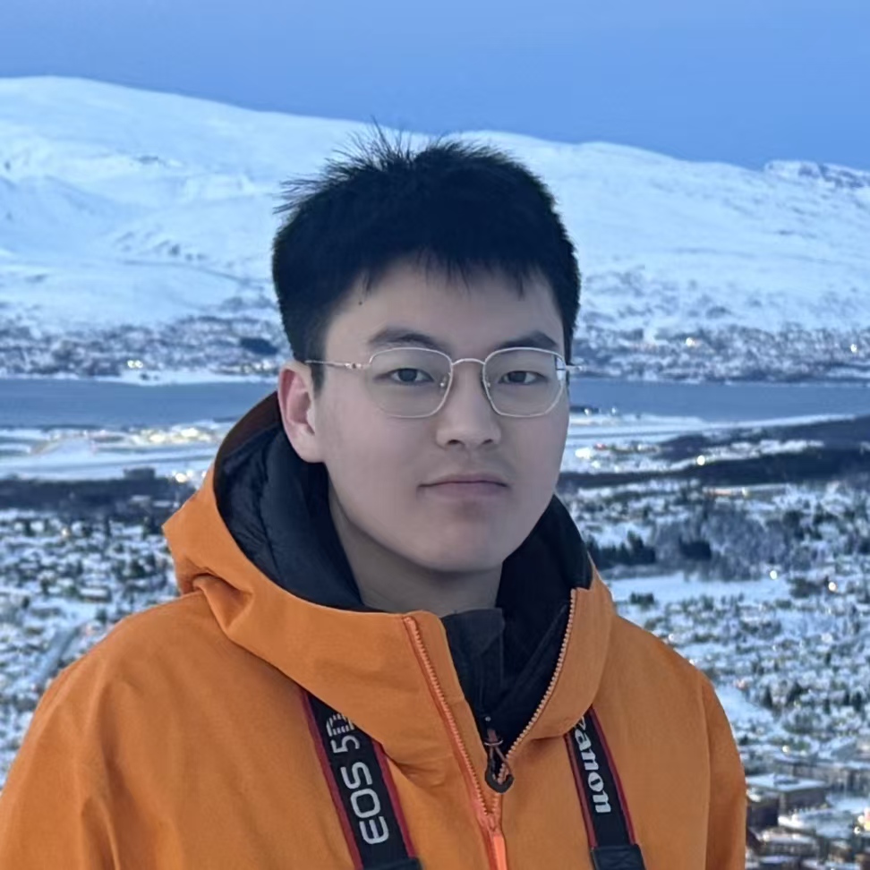
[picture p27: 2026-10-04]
lecturer&TAs pictures/congzhou.jpg

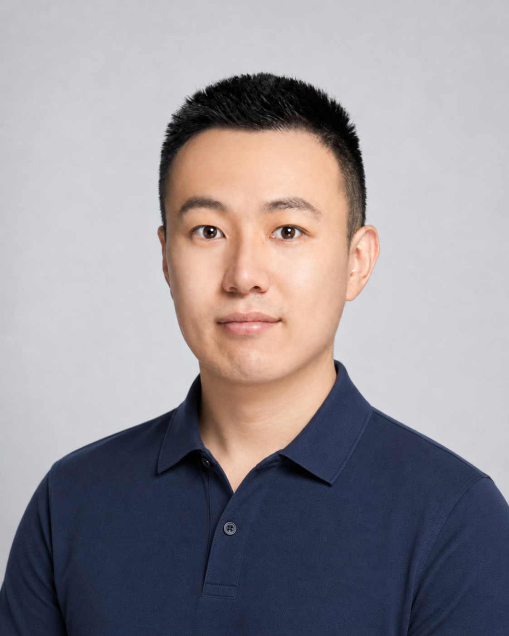
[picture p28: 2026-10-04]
lecturer&TAs pictures/hesun.png

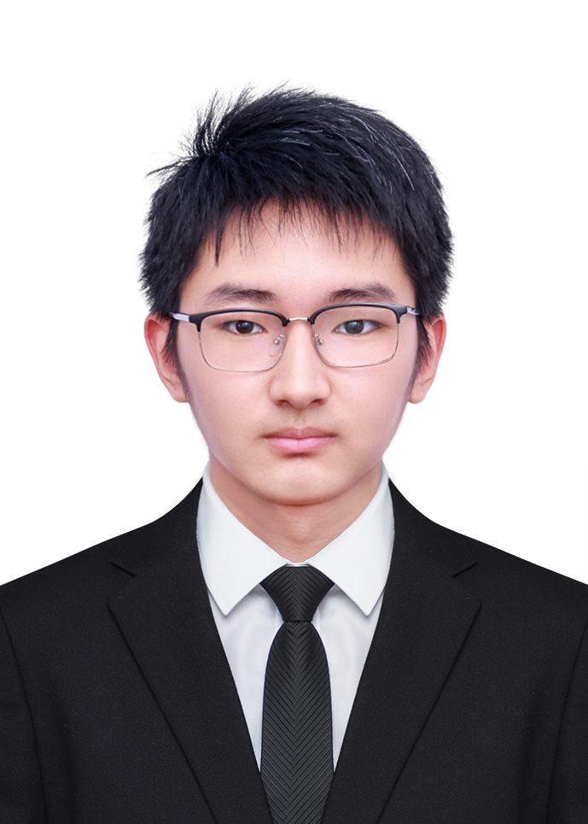
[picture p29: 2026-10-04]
lecturer&TAs pictures/linbocao.png

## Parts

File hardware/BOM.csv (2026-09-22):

Part | Model | Quantity | Specification | Source | Notes
Monochrome camera | VEN-161-61U3M | 1 | Bare board without lens mount; Sony IMX296; 1440 x 1080; 3.45 um pixels | https://en.daheng-imaging.com/show-93-2117-1.html | Use the bare-board variant for the printed housing
Mounted microlens array | MLAS10-F15-P300-AB | 1 | 300 um pitch; 14.6 mm focal length; 400-900 nm coating; 25.4 mm mount | https://en.lbtek.com/product/378
Lens tube | SM1-12.5A | 1 | SM1 internal and external threads; 12.5 mm internal thread length | https://en.lbtek.com/product/221 | Includes one SM1R retaining ring
Retaining ring | SM1R | 2 | SM1 external thread; 2.0 mm thick; 23.0 mm clear aperture; for 25.4 mm optics; black anodized 6061-T6 aluminum | https://en.lbtek.com/product/135#SM1R | Buy one extra if one is included with the lens tube
Front housing | Custom printed part | 1 | Camera board seat and SM1 opening |  | Choose a strong material with good heat resistance; STEP models linked in hardware/README.md; STL and print settings pending
Back housing | Custom printed part | 1 | Camera connector opening |  | Choose a strong material with good heat resistance; STEP models linked in hardware/README.md; STL and print settings pending
Housing screw | M2 | 4 | M2 thread | Hardware supplier | Joins the housing parts
Housing nut | M2x2 | 4 | Brass insert nut; supplier dimensions: length 3.5 mm; pilot hole diameter 3.2 mm; workpiece outer diameter 6.2 mm | Hardware supplier | Press into the housing recessed holes during printing
Camera cable | Compatible USB 3.0 cable | 1 | Match the camera connector and computer port |  | Accessory
Spanner wrench | SM1 compatible | 1 | For retaining rings | Optics supplier | Assembly tool

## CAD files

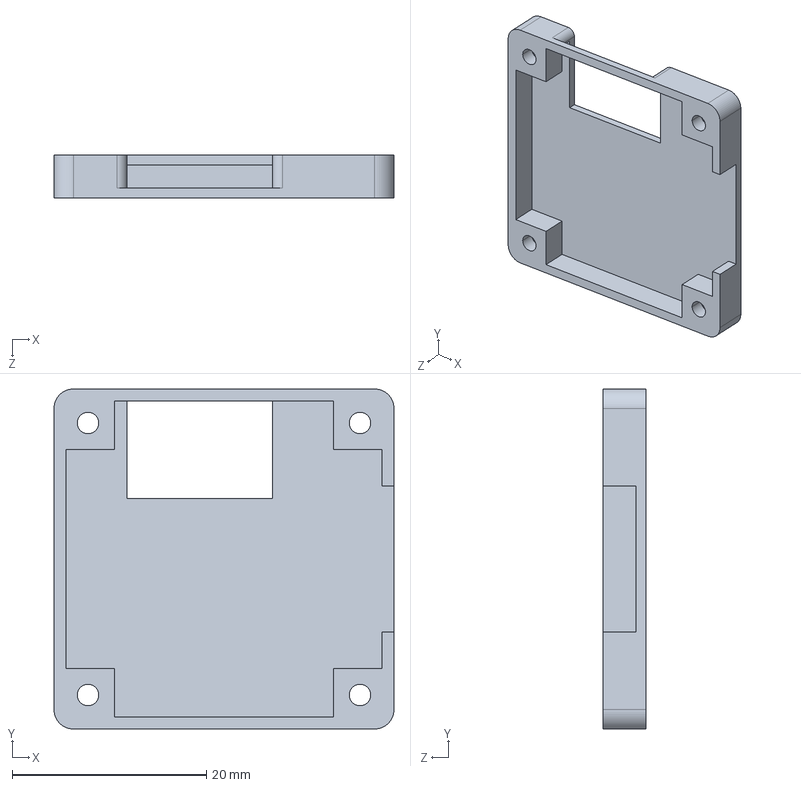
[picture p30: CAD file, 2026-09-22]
hartmann1.STEP
35.0 x 35.0 x 4.40 mm

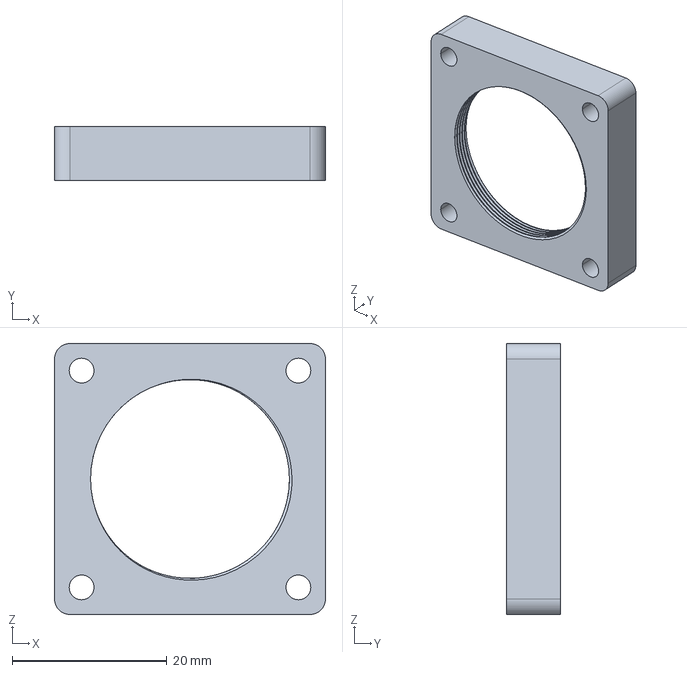
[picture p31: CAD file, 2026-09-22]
hartmann2 - 0923new.step
35.0 x 7.00 x 35.0 mm

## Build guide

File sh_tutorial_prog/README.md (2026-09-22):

# Offline Shack-Hartmann Image Analysis Tutorial

This tutorial shows how to calculate Zernike aberration coefficients from saved Shack-Hartmann images and optical parameters. You do not need to control a camera, a deformable mirror (DM), or a spatial light modulator (SLM).

The program uses two types of input:

- Experimental images: a reference image taken with no added aberration or in a known reference state, and a measurement image taken after adding Zernike aberrations.
- Optical parameters: the setup information stored in `config.yaml`. The program uses these values to convert pixel shifts into wavefront slopes and then fit Zernike coefficients.

## Optical Parameters in the Config File

`config.yaml` stores the parameters of the optical setup.

`camera.image_size_px`

The camera image size in pixels. For example, `[1440, 1080]` means an image width of 1440 px and a height of 1080 px. This value is mainly used to check whether the image size matches the configuration.

`camera.pixel_pitch_m`

The physical size of one camera pixel, in meters. For example, `3.45e-6` means 3.45 micrometers per pixel. The program uses this value to convert image shifts from pixels to meters.

`optics.wavelength_m`

The light wavelength in meters. For example, 635 nm red light is written as `635.0e-9`. The output Zernike coefficients describe phase in radians, so the wavelength is needed to convert between phase and wavefront height.

`optics.lenslet_pitch_m`

The distance between the centers of neighboring microlenses, in meters. For example, `300.0e-6` means a pitch of 300 micrometers. This value gives the approximate spot spacing and helps set the spot matching distance and gate size. A gate is the region used to select spots for analysis.

`optics.lenslet_focal_length_m`

The focal length of each microlens, in meters. In a Shack-Hartmann sensor, the spot shift at the focal plane divided by the microlens focal length gives the local wavefront slope. This value therefore directly affects the calculated Zernike coefficients.

`optics.sh_magnification`

The optical magnification from the wavefront plane being measured to the Shack-Hartmann sensor plane. If the optical system does not enlarge or reduce the wavefront, this is usually `1.0`.

`optics.zernike_aperture_diameter_m`

The effective aperture diameter used for Zernike fitting, in meters. This is the physical aperture used to normalize the Zernike modes, rather than the gate size. It affects the scale of the Zernike coefficients. If the measured and true coefficients differ by a nearly constant factor, check this parameter first.

## Program Structure

We suggest splitting the program into the following modules.

`config_loader.py`

Reads `config.yaml` and calculates values needed by later steps. For example:

```python
lenslet_pitch_px = lenslet_pitch_m / pixel_pitch_m
```

This is the approximate number of image pixels in one microlens pitch.

`spot_analysis.py`

Handles image processing and spot detection. It should:

1. Read PNG or NPY images.
2. Detect the center of each spot.
3. Match spots in the reference and measurement images to find each spot's displacement, `dx_px, dy_px`.

The expected result is a table of matched spots. Each row should include the reference position, the measurement position, and the displacement between them.

`calibration.py`

Uses calibration images to find the information needed for later calculations. It usually needs four images: reference, defocus, x tilt, and y tilt.

The defocus image is used to estimate the center of the spot array. The tilt images are used to find the pupil x and y directions in image coordinates.

The expected output is a calibration file, such as `pupil_center_calibration.json`. It should contain:

- Center position: `center_x_px, center_y_px`
- Pupil x direction: `pupil_x_axis_image`
- Pupil y direction: `pupil_y_axis_image`
- Gate size
- Number of spots used in the calculation

Use the same calibration file for later measurement images, as long as the optical setup and calibration conditions stay the same.

`wavefront_reconstruction.py`

Converts spot displacements into Zernike coefficients. The main steps are:

1. Convert image coordinates to pupil coordinates.
2. Convert spot displacements to local wavefront slopes.
3. Build a matrix of Zernike mode slopes using the effective aperture in the configuration.
4. Solve for the Zernike coefficients using least squares or a regularized method.

The expected result is a table, such as `measured_zernike_coeffs.csv`. Each row represents one Zernike mode and contains `zernike_j`, the mode name, and the measured phase coefficient `coeff_rad`.

`analyze_zernike.py`

This is the main program. It connects the modules above and should:

1. Read the configuration.
2. Read the calibration file.
3. Read the reference image for one dataset group.
4. Read each measurement image in turn.
5. Detect spots, match them, apply the gate, and calculate Zernike coefficients.
6. Compare the true and measured coefficients if true values are included in the dataset.

## Dataset Structure

The dataset is organized as follows:

```text
dataset/
  first_10_zernike/
    reference_flat.png
    sample_01_j02_tilt_x/
      measurement.png
      true_zernike_phase_coeffs.csv
    sample_02_j03_tilt_y/
      measurement.png
      true_zernike_phase_coeffs.csv

  last_10_zernike/
    reference_flat.png
    sample_01_j12_secondary_astig_45/
      measurement.png
      true_zernike_phase_coeffs.csv

  mixed_zernike/
    reference_flat.png
    sample_01_mixed/
      measurement.png
      true_zernike_phase_coeffs.csv
```

Each group needs only one `reference_flat.png`. All measurement images in that group are compared with this reference image.

Each sample folder contains one `measurement.png`. It can also contain `true_zernike_phase_coeffs.csv` for checking the results.

## Suggested Coding Steps

### Step 1. Read the Configuration

Start with a simple loader. Check that it reads the image size, pixel size, microlens pitch, focal length, wavelength, and effective Zernike aperture correctly. You do not need to process images yet.

Expected result: the loader can print calculated values such as `lenslet_pitch_px`.

### Step 2. Read an Image and Detect Spots

Start with the reference image. Find all spot centers and plot them on the image to check their positions.

Expected result: the number of detected spots is reasonable, the detected centers cover the array, and there are few false detections near the edges.

### Step 3. Match Reference and Measurement Spots

Detect spots separately in the reference and measurement images from the same group. Then match them using their nearest neighbors.

Expected result: each matched spot has a displacement vector. For tilt, the vectors should point in roughly the same direction. For defocus, they should point roughly toward or away from the center.

### Step 4. Run Calibration

Use the defocus image to estimate the pupil center. Use the two tilt images to estimate the pupil x and y directions. Save these results in a calibration file.

Expected result: `pupil_center_calibration.json`, plus displacement plots for the defocus, x tilt, and y tilt images showing the spots kept by the gate.

### Step 5. Calculate Zernike Coefficients

Read the reference image, measurement image, and calibration file. Convert spot displacements to wavefront slopes, then fit the Zernike coefficients.

Expected result: `measured_zernike_coeffs.csv`. If true coefficients are available, also plot a comparison of the true and measured values.

### Step 6. Check the Results

If all measured values are smaller or larger than the true values by a nearly constant factor, first check `zernike_aperture_diameter_m`, the microlens focal length, and the pixel size.

If some modes have the wrong sign, first check whether the pupil x or y direction is reversed.

If errors are much larger for higher-order modes, first check the gate size, the quality of edge spots, and whether spot matching is reliable.

## Output Files

After a full analysis, we suggest saving these files:

`measured_zernike_coeffs.csv`

The measured Zernike coefficients.

`true_vs_measured_zernike_coeffs.csv`

A table comparing the true and measured coefficients.

`true_vs_measured_zernike.png`

A bar chart comparing the true and measured coefficients.

`spot_displacements_gate.png`

A plot of the spot displacements selected by the gate for fitting.

These files can be used to check the program's results and explain the analysis steps in a course report.

## Main Idea

Shack-Hartmann image analysis follows four basic steps:

1. Find each spot's position in the image.
2. Find the local displacement by subtracting the reference position from the measurement position.
3. Use the microlens focal length to convert the displacement into a wavefront slope.
4. Fit the measured slopes using the theoretical slopes of Zernike modes.

You can calculate Zernike aberration coefficients entirely offline, as long as the reference image, measurement image, optical parameters, and calibration file all correspond to the same setup and conditions.

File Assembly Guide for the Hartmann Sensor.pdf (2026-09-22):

## Assembly Guide for the Hartmann Sensor

## 1 Assembling the Hartmann Sensor

Before handling any optical or electronic components, put on a pair of clean gloves.

Important

Always wear gloves during the assembly process to prevent fingerprints and dust on the optical and electronic components.

### 1.1 Step 1. Install the Camera PCB

Take the front housing, which can be identified by the groove for the camera PCB and the SM1 opening.

Place the camera PCB into the groove. Make sure the sensor faces the SM1 opening.

The PCB may move slightly at this stage. This is normal and it will be secured after the back housing is installed.

### 1.2 Step 2. Install the Back Housing

Place the back housing onto the camera PCB.

Align the opening in the back housing with the metal connector on the camera PCB.

Insert the four screws and tighten each screw a few turns. After all four screws are in place, tighten them gradually.

Important

The housing may slightly press on the camera chip. When you feel resistance, stop tightening. Do not tighten the screws with strong force.

Starting Point for This Course

Starting Point

In this course, your Hartmann sensor housing may already be assembled.
If you receive a sensor body like the one shown below, you do not need to repeat Step 1 and Step 2.
You can start directly from Step 3. Assemble the Lens Tube.

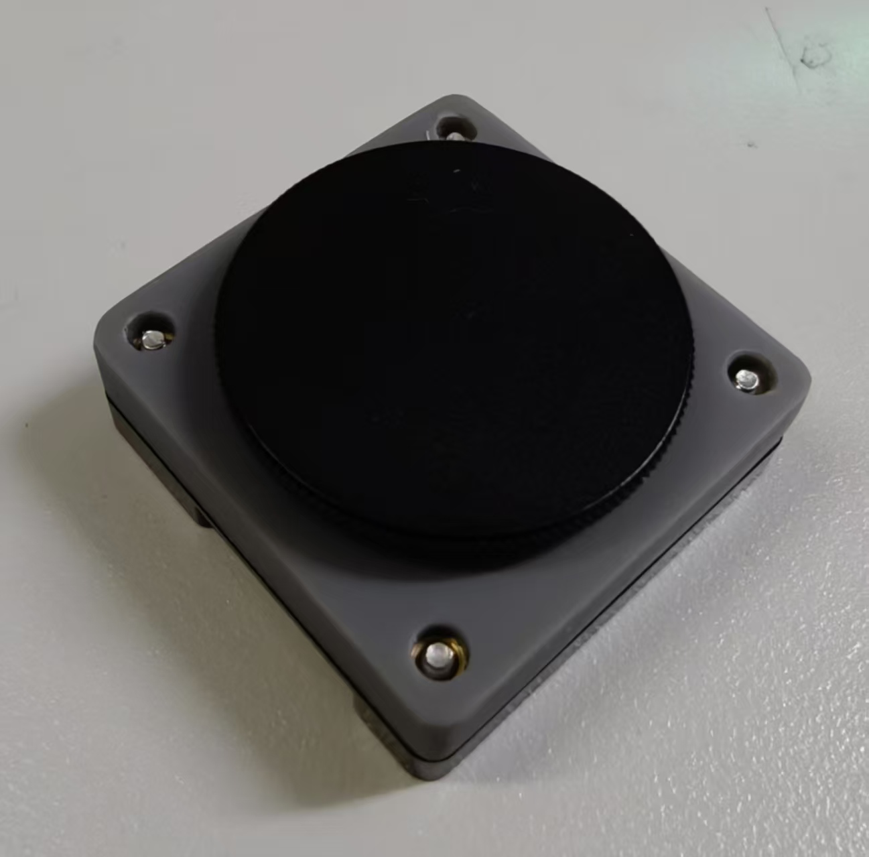
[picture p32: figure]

Figure 1: Assembled Hartmann sensor housing without the lens tube. If you receive this part, you can start from the lens tube assembly step.

### 1.3 Step 3. Assemble the Lens Tube

Use the SM1 spanner wrench to install one retaining ring into the lens tube.

Screw it near the bottom of the lens tube. It does not need to be tight.

Place the mounted MLA into the lens tube. The MLA has no front or back side, so either side can face the camera.

Install the second retaining ring. Tighten it until the MLA no longer moves.

Important

Do not tighten the retaining ring too much. Stop when you feel a little resistance.

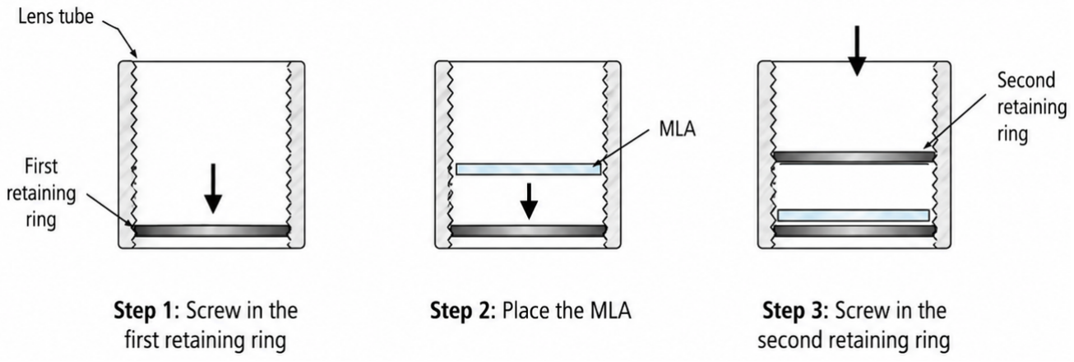
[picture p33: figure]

Figure 2: Assembly of the MLA inside the lens tube.

### 1.4 Step 4. Attach the Lens Tube

Screw the assembled lens tube into the SM1 opening on the front housing.

Turn the lens tube slowly. If the thread feels tight because of the 3D printed housing, you can stop when you feel clear resistance.

The lens tube does not need to be fully tightened or screwed all the way to the end.

Important

The housing is 3D printed, so the thread may feel tight. Do not force the lens tube. Stop when you feel clear resistance.The lens tube does not need to be screwed all the way in.

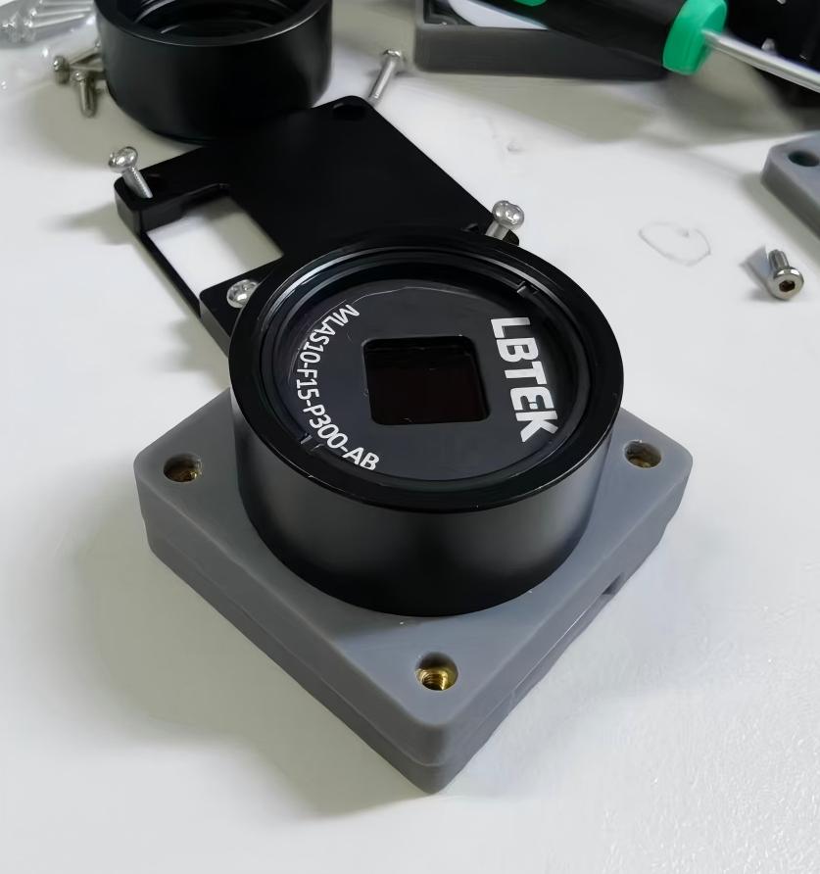
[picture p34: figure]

Figure 3: Attach the assembled lens tube to the front housing.

### 1.5 Step 5. Connect the Camera

Connect the camera to your computer and open the Galaxy Viewer software.

The software icon looks like this:

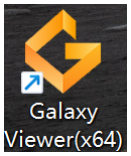
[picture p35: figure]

Figure 4: Galaxy Viewer software icon.

After opening the software, find the camera in the left device list.

Double-click the camera name to open it.

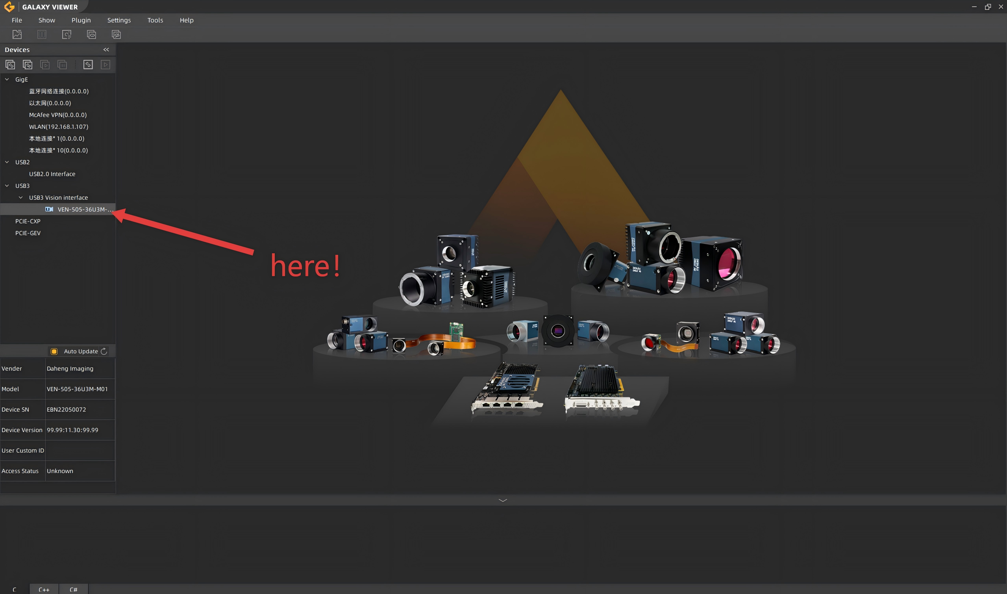
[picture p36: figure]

Figure 5: Find the camera in the device list and double-click it.

After the camera window opens, click the acquisition button on the top toolbar to start imaging.

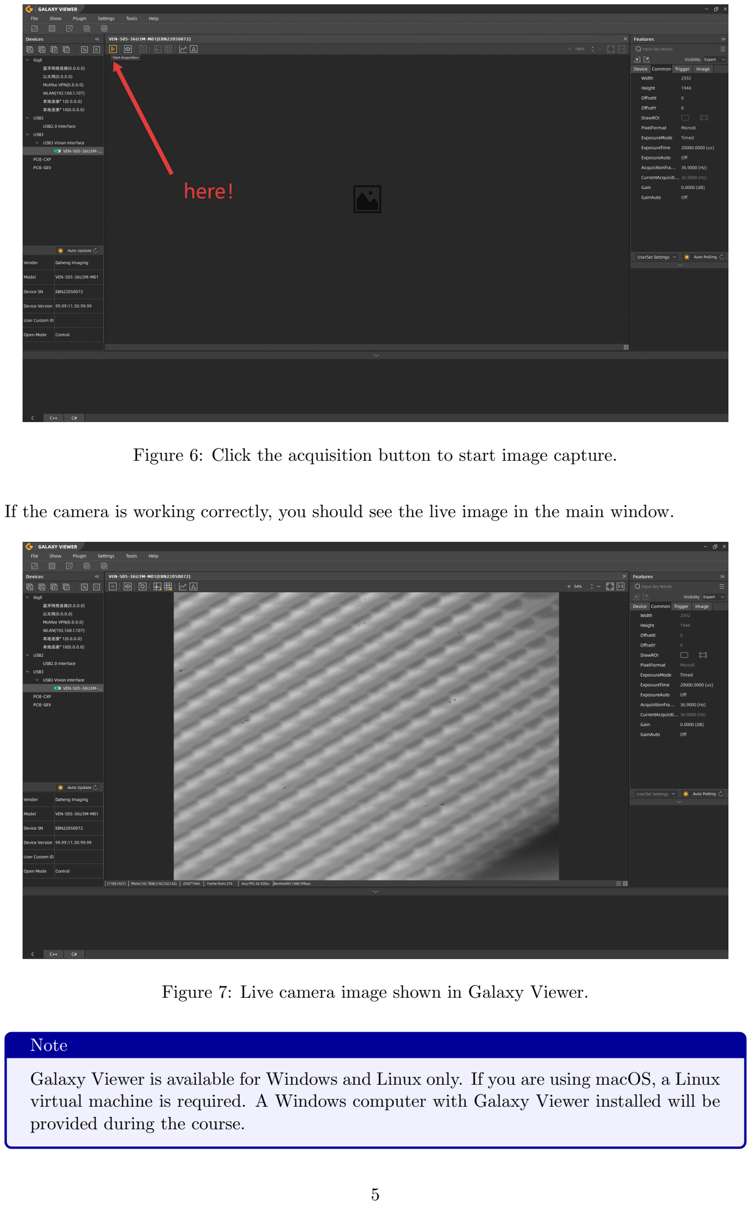
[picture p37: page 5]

Figure 6: Click the acquisition button to start image capture.

If the camera is working correctly, you should see the live image in the main window.

Figure 7: Live camera image shown in Galaxy Viewer.

Note

Galaxy Viewer is available for Windows and Linux only. If you are using macOS, a Linux virtual machine is required. A Windows computer with Galaxy Viewer installed will be provided during the course.

### 1.6 Step 6. Check the Spot Pattern

Place the Hartmann sensor in the prepared optical setup with a collimated beam.

Adjust the position of the sensor until the beam passes through the center of the MLA.

You should see a regular array of large bright spots on the screen.

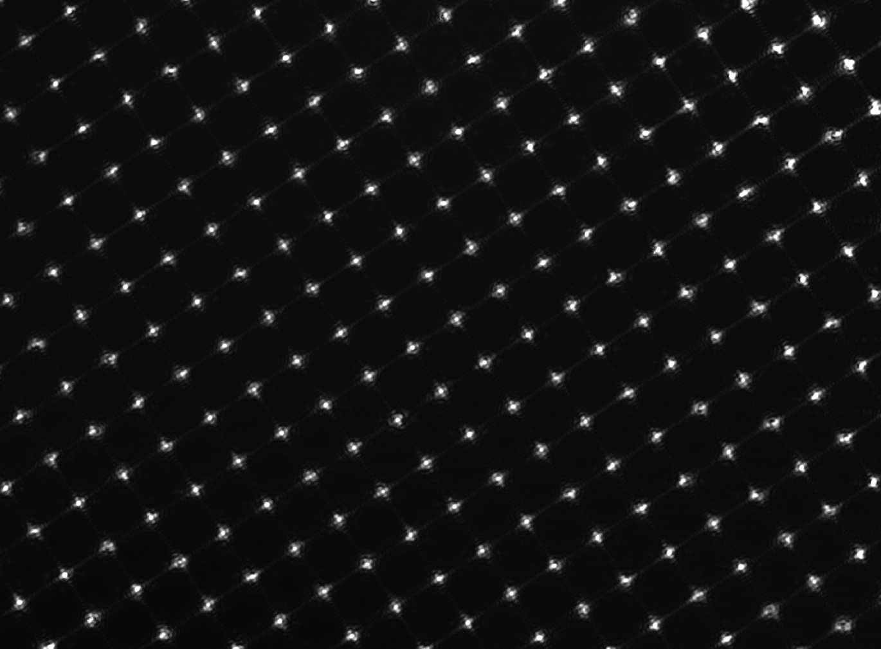
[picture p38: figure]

Figure 8: Initial spot pattern after installing the MLA. At this stage, the MLA has not been fully adjusted yet, so the spot array may be tilted and the spots may not be at the best focus.

### 1.7 Step 7. Focus Adjustment

Unscrew the lens tube from the housing.

Remove the outer retaining ring and take out the MLA. Move the inner retaining ring by about two turns, then put the MLA back and install the outer retaining ring again.

Screw the lens tube back onto the housing and check the spot pattern in the Galaxy software.

Repeat these steps until the spots become as small as possible.

### 1.8 Step 8. Align the MLA

Keep the inner retaining ring in place.

Loosen the outer retaining ring slightly and rotate the MLA until its edges are parallel to the edges of the square housing.

Tighten the outer retaining ring again. It only needs to hold the MLA in place, so do not tighten it too much.

## 2 Final Expected Result

After the Hartmann sensor is assembled and adjusted correctly, you should see a regular spot array like the image below.

The spots should be small, clear, and arranged in a regular grid. This means the MLA and the camera are well aligned.

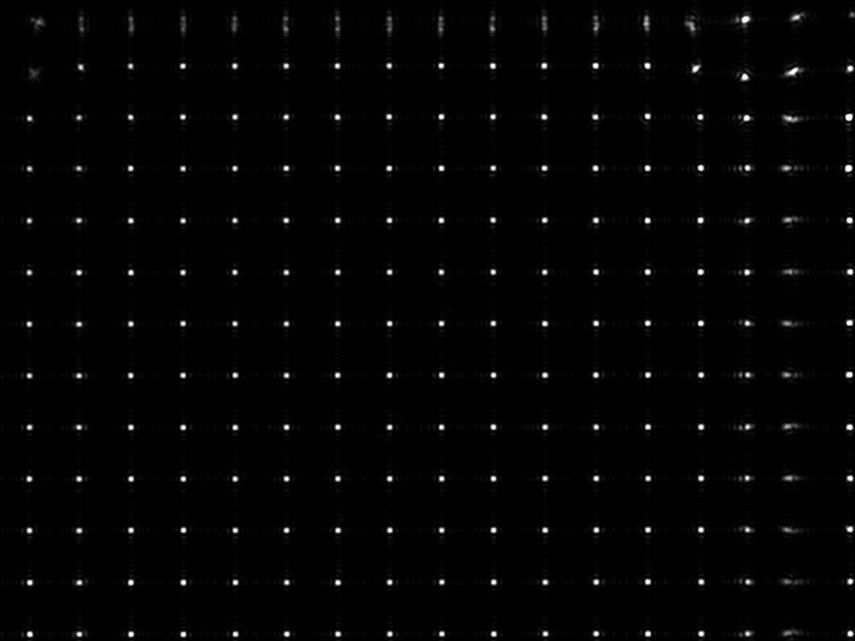
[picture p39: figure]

Figure 9: Final expected Shack-Hartmann spot pattern after assembly and adjustment.

## Have Fun!

You have now finished the Hartmann sensor assembly and the basic Shack-Hartmann analysis tutorial.

We hope this tutorial helps you understand how a Hartmann sensor works and how to assemble it.

## Have fun with your Hartmann sensor!

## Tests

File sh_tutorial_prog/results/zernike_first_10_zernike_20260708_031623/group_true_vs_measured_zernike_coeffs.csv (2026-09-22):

zernike_j | n | m | name | true_phase_coeff_rad | measured_phase_coeff_rad | error_phase_coeff_rad | sample
2 | 1 | 1 | tilt_x | 10.0 | 6.153204767171614 | -3.846795232828386 | sample_01_j02_tilt_x
3 | 1 | -1 | tilt_y | 0.0 | -0.7207278954713559 | -0.7207278954713559 | sample_01_j02_tilt_x
4 | 2 | 0 | defocus | 0.0 | 0.030959570243600174 | 0.030959570243600174 | sample_01_j02_tilt_x
5 | 2 | -2 | astig_45 | 0.0 | -0.01171405222989951 | -0.01171405222989951 | sample_01_j02_tilt_x
6 | 2 | 2 | astig_0 | 0.0 | 0.0 | 0.0 | sample_01_j02_tilt_x
7 | 3 | -1 | coma_y | 0.0 | 0.0 | 0.0 | sample_01_j02_tilt_x
8 | 3 | 1 | coma_x | 0.0 | 0.02638960933904555 | 0.02638960933904555 | sample_01_j02_tilt_x
9 | 3 | -3 | trefoil_y | 0.0 | 0.0 | 0.0 | sample_01_j02_tilt_x
10 | 3 | 3 | trefoil_x | 0.0 | 0.0 | 0.0 | sample_01_j02_tilt_x
11 | 4 | 0 | spherical | 0.0 | 0.057861359249711336 | 0.057861359249711336 | sample_01_j02_tilt_x
12 | 4 | -2 | secondary_astig_45 | 0.0 | -0.04039184463765529 | -0.04039184463765529 | sample_01_j02_tilt_x
13 | 4 | 2 | secondary_astig_0 | 0.0 | 0.12242684299681292 | 0.12242684299681292 | sample_01_j02_tilt_x
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

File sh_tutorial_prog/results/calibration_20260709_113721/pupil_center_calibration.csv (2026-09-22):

center_x_px | center_y_px | gate_half_cols | gate_half_rows | reference_spots | defocus_final_gated_spots | tilt_x_final_gated_spots | tilt_y_final_gated_spots | axis_dot | axis_determinant | axis_angle_between_deg | pupil_x_axis_image_x | pupil_x_axis_image_y | pupil_y_axis_image_x | pupil_y_axis_image_y | pupil_y_axis_orthogonalized_image_x | pupil_y_axis_orthogonalized_image_y
637.6877296215351 | 680.4975894163075 | 5.0 | 5.0 | 241 | 100 | 100 | 100 | -0.0589025893802567 | -0.998263735174378 | 93.37682435397548 | 0.9995263939403201 | 0.03077316715354733 | -0.028154955971149725 | -0.9996035706490162 | 0.03077316715354733 | -0.9995263939403201

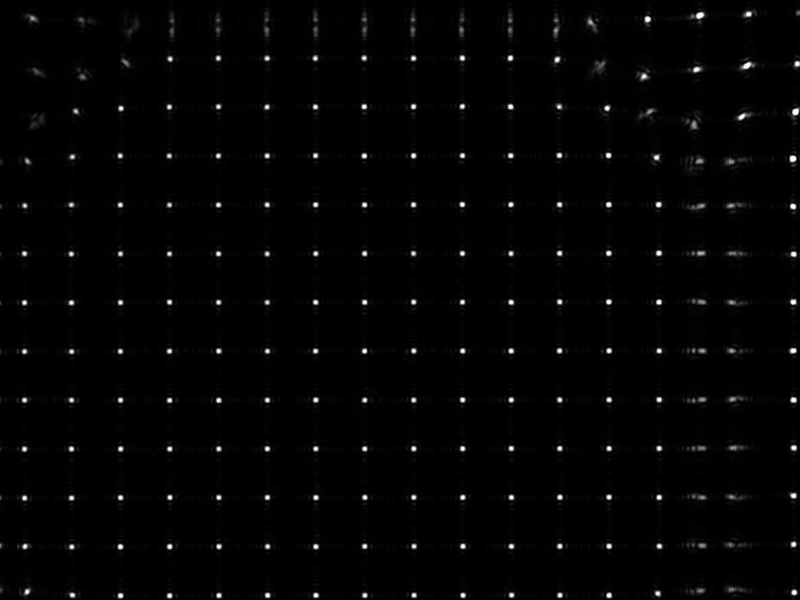
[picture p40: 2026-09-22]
sh_tutorial_prog/calibration_pics/measurement_defocus.png

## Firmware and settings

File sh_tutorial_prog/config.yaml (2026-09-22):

# Objective optical information for the offline Shack-Hartmann tutorial.
# Length uses m, wavelength uses m, image coordinates use px.

paths:
  results_dir: results

camera:
  image_size_px: [1440, 1080]  # [width, height]
  pixel_pitch_m: 3.45e-6

optics:
  wavelength_m: 635.0e-9
  lenslet_pitch_m: 300.0e-6
  lenslet_focal_length_m: 14.6e-3
  sh_magnification: 1.0
  zernike_aperture_diameter_m: 4.4e-3

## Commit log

2026-09-22 Publish ICCP adaptive optics course website and tutorial
    [group_true_vs_measured_zernike_coeffs.csv, manifest.csv, measured_zernike_coeffs.csv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]
2026-09-22 Add sensor hardware parts and assembly page
    [BOM.csv]
2026-09-22 Integrate hardware and assembly into course homepage
2026-09-22 Publish camera housing STEP models and download links
    [BOM.csv, hartmann1.STEP, hartmann2 - 0923new.step]
2026-09-22 Move housing model downloads into hardware table
2026-09-22 Bundle housing STEP models into one ZIP download
2026-09-22 Specify M2 fasteners and nut insertion during printing
    [BOM.csv]
2026-09-22 Add SM1R specifications and housing material guidance
    [BOM.csv]
2026-09-22 Specify M2x2 housing insert nuts and remove screw length note
    [BOM.csv]
2026-09-22 Document supplier dimensions for M2x2 housing inserts
    [BOM.csv]
2026-09-22 Embed assembly video and enlarge site typography
2026-09-22 Crop assembly video borders and unify button hover effects
2026-09-22 Fix button hover feedback and make result cards fully clickable
2026-09-22 Simplify hardware copy and enlarge assembly heading
2026-09-22 Remove materials subtitle and card category labels
2026-10-04 Add a "Visit Our Lab Website" button
